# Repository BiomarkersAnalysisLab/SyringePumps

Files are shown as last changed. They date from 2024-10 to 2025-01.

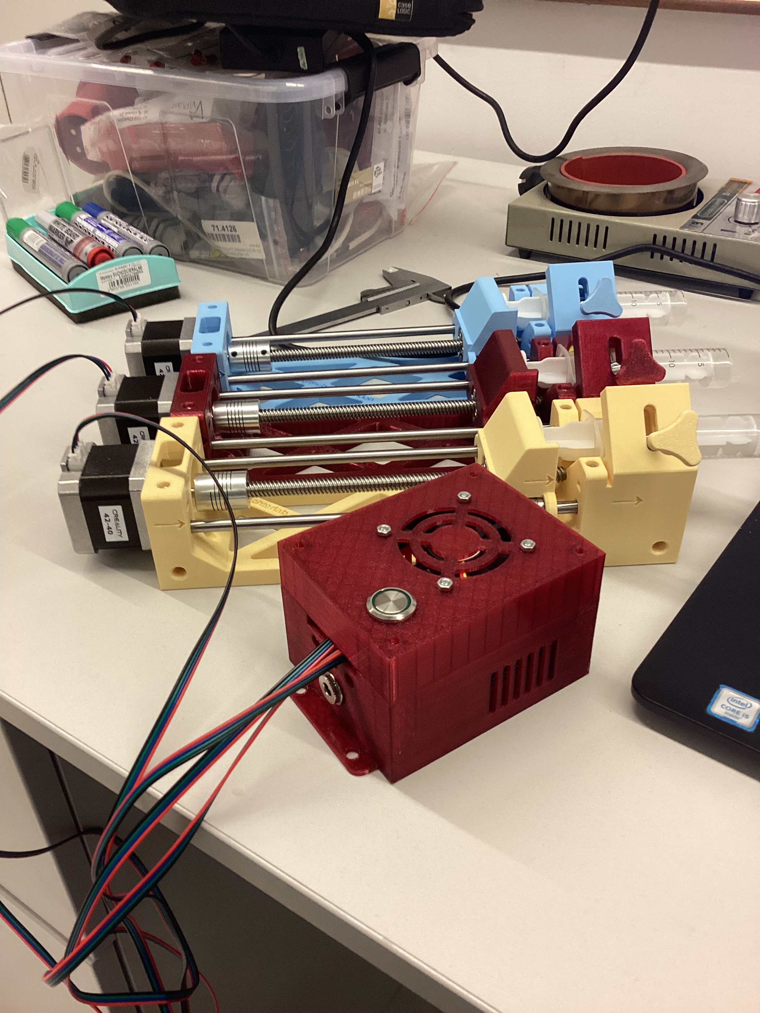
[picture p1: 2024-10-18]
Images/IMG_0060.JPEG

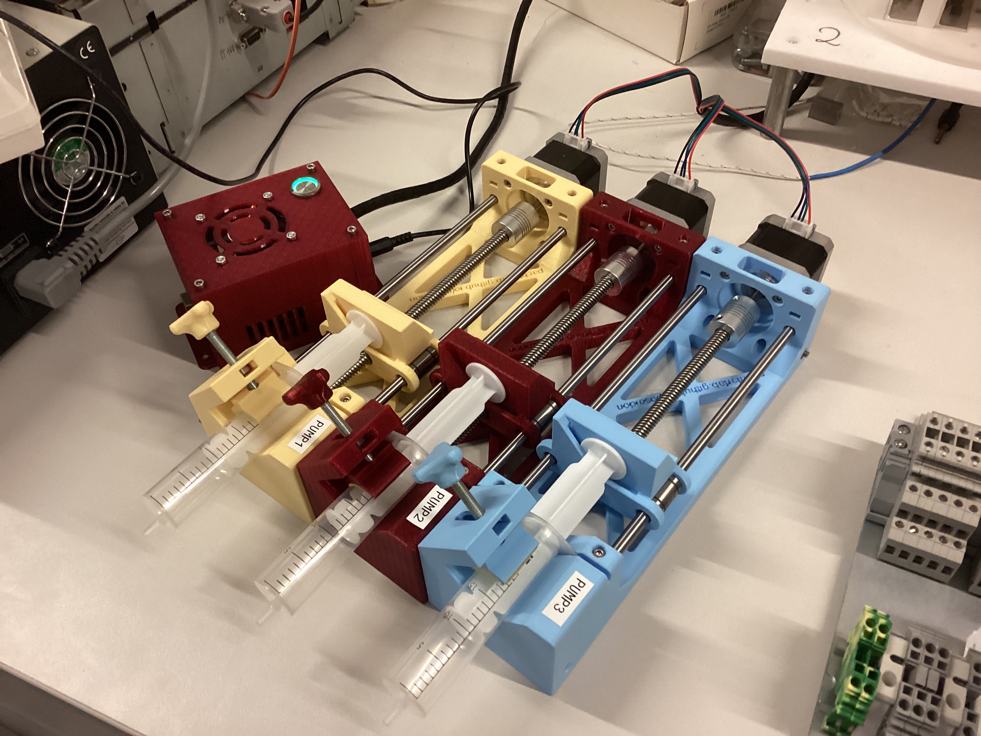
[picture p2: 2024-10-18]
Images/IMG_0064.JPEG

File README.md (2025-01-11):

Obraz1

Project realised by AGH Biomarkers Analysis Lab as a part of NCN SONATA BIS 12:  "Badania nad możliwością realizacji bioczujników do detekcji biomarkerów cukrzycy i NAFLD otrzymywanych w technologii TWD/GLAD" nr 2022/46/E/ST7/00008.

The main objective of the project was to create highly accurate pumps allowing precise dispension of fluids, with realatively low cost. 

The project was based on opensource project: https://github.com/pachterlab/poseidon/tree/release under the BSD-2-Clause license with modifications explained in "Changes_in_original_design.docx" file.

All the modified 3D models are available, and the test were conducted to prove the efficiency of the pumps.

pump


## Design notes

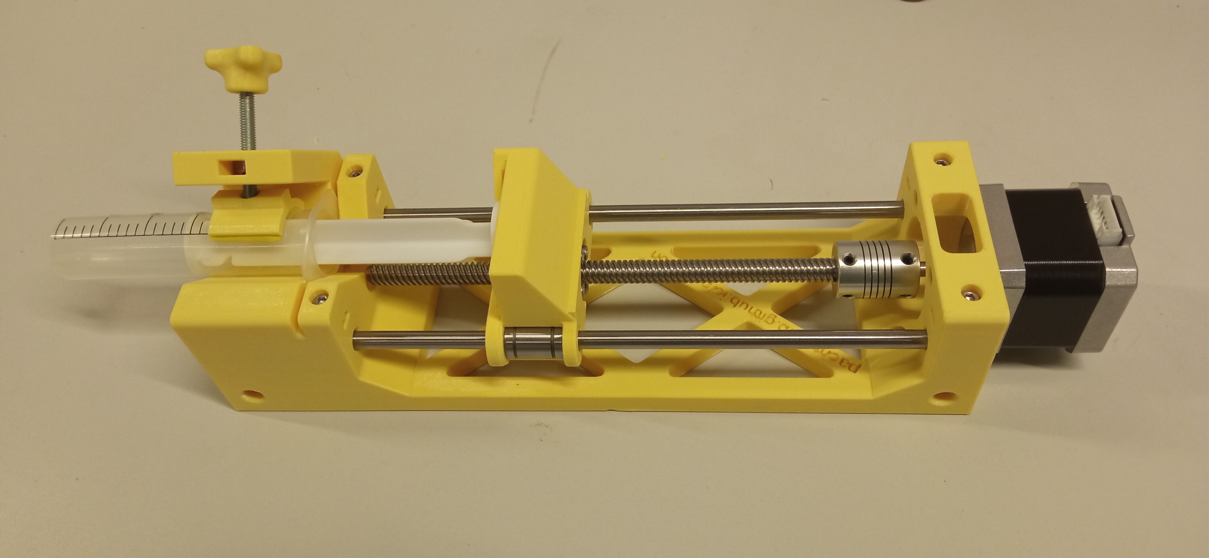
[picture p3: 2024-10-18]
Images/pump.jpg

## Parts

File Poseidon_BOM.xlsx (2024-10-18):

Poseidon Pumps
Total for 3 pumps | $120.70 |  |  |  | Per pump total | 43.45
Part Number | Item Description | Package Cost | Items for 3 pumps | Items per pump | Cost for 3 pumps | Cost per pump | Cost for single pump | Retailer | Items per pack | Price per item | Link
1 | Nema 17 Stepper Motor (Bipolar) | 33.99 | 3 | 1 | 33.99 | 11.33 | 33.99 | Amazon | 3 | 11.33 | https://www.amazon.com/Stepper-Holding-Printer-Beauty-Star/dp/B075S98D46
2 | 5mmx8mm Motor Shaft Coupling | 22 | 3 | 1 | 6.60 | 2.2 | 22 | Amazon | 10 | 2.20 | https://www.amazon.com/Aluminum-Flexible-Coupling-Printing-Pack/dp/B01EFFBM4I?s=industrial
3 | 6mm Steel Rod (length 200mm) | 7.12 | 6 | 2 | 21.36 | 7.12 | 7.12 | Amazon | 2 | 3.56 | https://www.amazon.com/Steel-Round-Turning-Lathe-200mm/dp/B00LUSVKVY
4 | 6mm Linear Bearing | 12.49 | 6 | 2 | 6.24 | 2.081666667 | 12.49 | Amazon | 12 | 1.04 | https://www.amazon.com/uxcell-6mmx12mmx19mm-Linear-Bushing-Bearing/dp/B01MTLSZFQ?s=industrial
5 | TR8x2 Lead Screw (length 170mm) | 9.14 | 3 | 1 | 5.48 | 1.828 | 9.14 | Amazon | 5 | 1.83 | https://www.amazon.com/uxcell-170mm-Stainless-Threaded-Fasteners/dp/B01M4L8JDC?s=industrial
6 | TR8x2 nut | 4.99 | 3 | 1 | 7.49 | 2.495 | 4.99 | Amazon | 2 | 2.50 | https://www.amazon.com/ReliaBot-Screw-Thread-Diameter-Printer/dp/B07TZCHP1N
7 | M3x16 socket head screws to mount motor | 6.35 | 24 | 4 | 1.52 | 0.254 | 6.35 | Amazon | 100 | 0.06 | https://www.amazon.com/Socket-Screw-Thread-stainless-100pcs/dp/B077XVVWYW
8 | M3x10 socket head screws (hold rod in place, length 10mm) | 7.8 | 12 | 4 | 1.70 | 0.5672727273 | 7.8 | Amazon | 55 | 0.14 | https://www.amazon.com/uxcell-M3x10mm-Thread-Stainless-Socket/dp/B01MFA9YEP?s=industrial
9 | M3 nut (hold rod in place) | 5.2 | 1 | 4 | 0.05 | 0.208 | 5.2 | Amazon | 100 | 0.05 | https://www.amazon.com/100Pcs-Female-Thread-Fastener-Silver/dp/B00GYS1SXU?s=industrial
10 | M5 knob (hold syringe in place) | 0 | 3 | 1 | 0.00 | 0 | 0 |  | 10 | 0.00 | https://www.thingiverse.com/thing:774472
11 | M5 nut | 6.99 | 3 | 1 | 0.21 | 0.0699 | 6.99 | Amazon | 100 | 0.07 | https://www.amazon.com/Nuts-M5-0-8-Stainless-Steel-100pcs/dp/B0BLBLBP93?sp_csd=d2lkZ2V0TmFtZT1zcF9hdGY
12 | M5 hex screw (length 40mm) | 8.99 | 3 | 1 | 1.08 | 0.3596 | 8.99 | Amazon | 25 | 0.36 | https://www.amazon.com/Socket-Screws-Stainless-Metric-Machine/dp/B09LYK1TH1
13 | Stepper driver a4988 | 7.99 | 3 | 1 | 7.99 | 2.663333333 | 7.99 | Amazon | 3 | 2.66 | https://www.amazon.com/WWZMDiB-Stepstick-Stepper-Printer-Suitable/dp/B0BFQZWT6R?sp_csd=d2lkZ2V0TmFtZT1zcF9hdGY
14 | 12V power unit (end stripped to fit CNC shield power input) | 13.99 | 3 | 1 | 13.99 | 4.663333333 | 13.99 | Amazon | 4 | 4.66 | https://www.amazon.com/Kastar-AC-Adapter-Power-LCD/dp/B003TUMDWG?s=electronics
15 | Arduino Uno | 8.99 | 1 | 0.33 | 8.99 | 2.9667 | 8.99 | Amazon | 1 | 8.99 | https://www.amazon.com/WWZMDiB-ATmega328P-microcontroller-Development-Compatible/dp/B0BV9XFQ5T
16 | CNC Shield | 7.99 | 1 | 0.33 | 4.00 | 1.31835 | 7.99 | Amazon | 2 | 4.00 | https://www.amazon.com/HiLetgo%C2%AE-Engraver-Printer-Expansion-Arduino/dp/B01D2HL9T8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
17 | 1M Bipolar Stepper Motor Cable 4pin Nema17 Stepper Motor Cable | 10 | 3 | 1 | 30 | 10 | 10 | Amazon | 1 |  | https://www.amazon.pl/SIENOC-krokowy-silnika-krokowego-dlugo%C5%9B%C4%87/dp/B077N4RYNX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

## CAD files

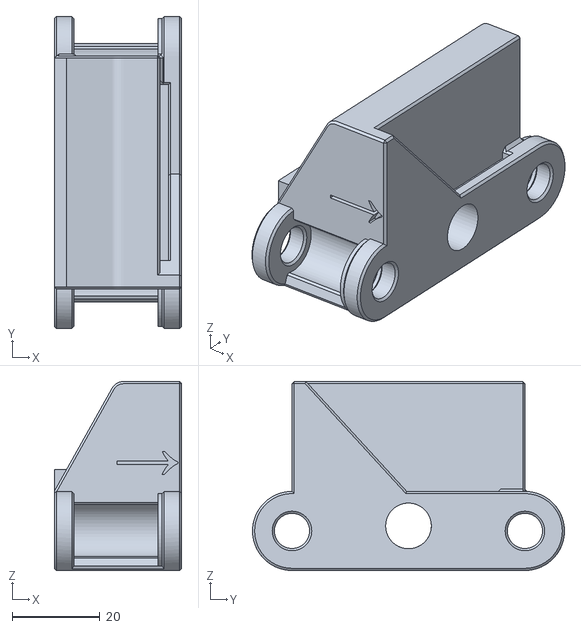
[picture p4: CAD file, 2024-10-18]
3D models/STL/Carriage+v1.stl
29.0 x 71.0 x 43.0

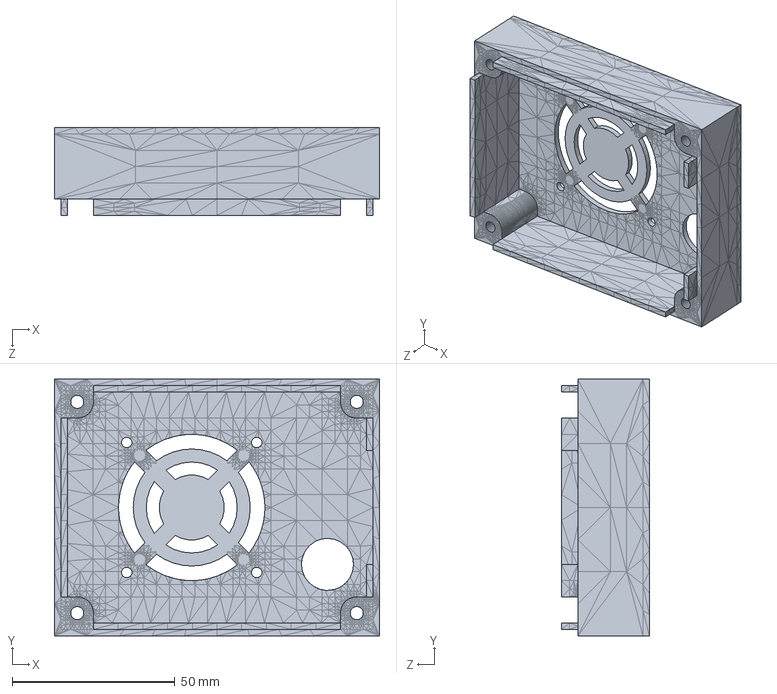
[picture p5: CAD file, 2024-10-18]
case-pump-driver/Modyfikacja/obudowa_gora_50x50.SLDPRT
100.0 x 79.0 x 27.0 mm

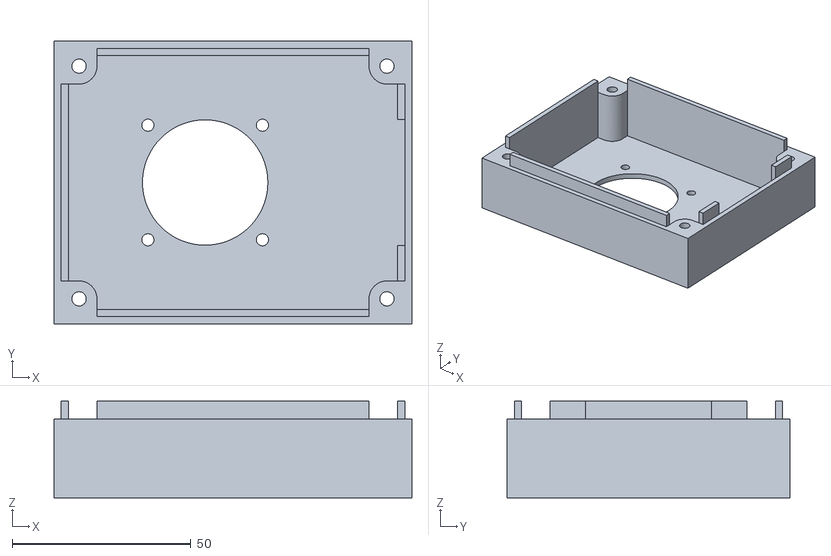
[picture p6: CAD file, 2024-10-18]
case-pump-driver/obudowa_gora_40x40.stl
100.0 x 79.0 x 27.0

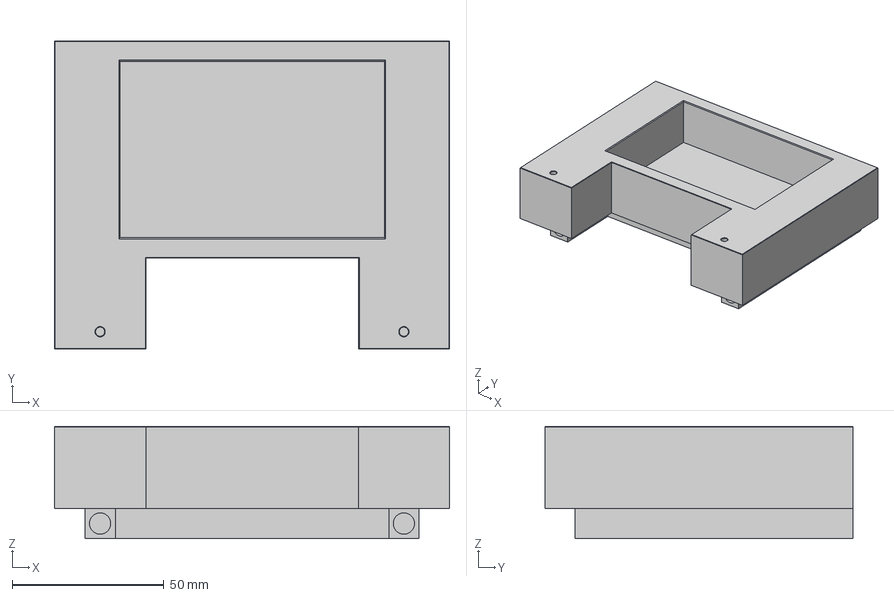
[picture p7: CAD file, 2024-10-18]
Microscope_Desk/STOLIK.step
130.0 x 101.5 x 37.0 mm

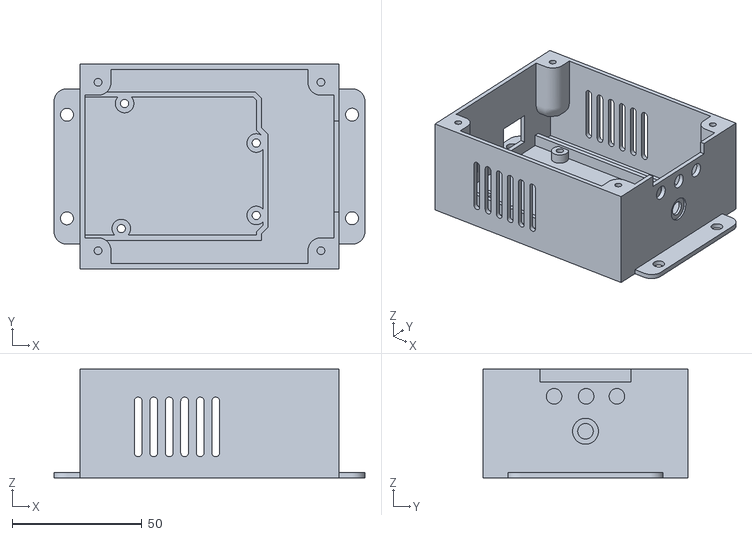
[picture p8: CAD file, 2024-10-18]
case-pump-driver/obudowa_dol.stl
120.0 x 79.0 x 42.0

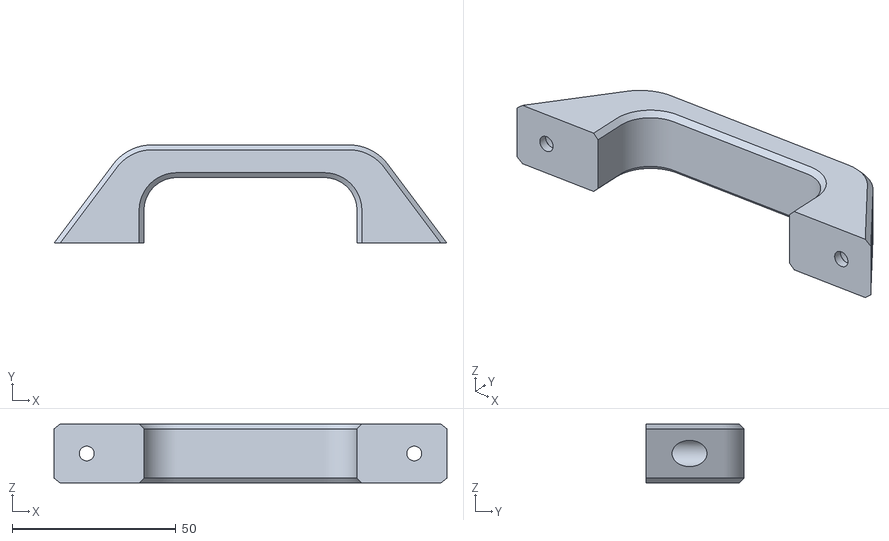
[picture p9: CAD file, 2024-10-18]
Microscope_Desk/Handle_MEDIUM.stl
120.0 x 30.0 x 18.0

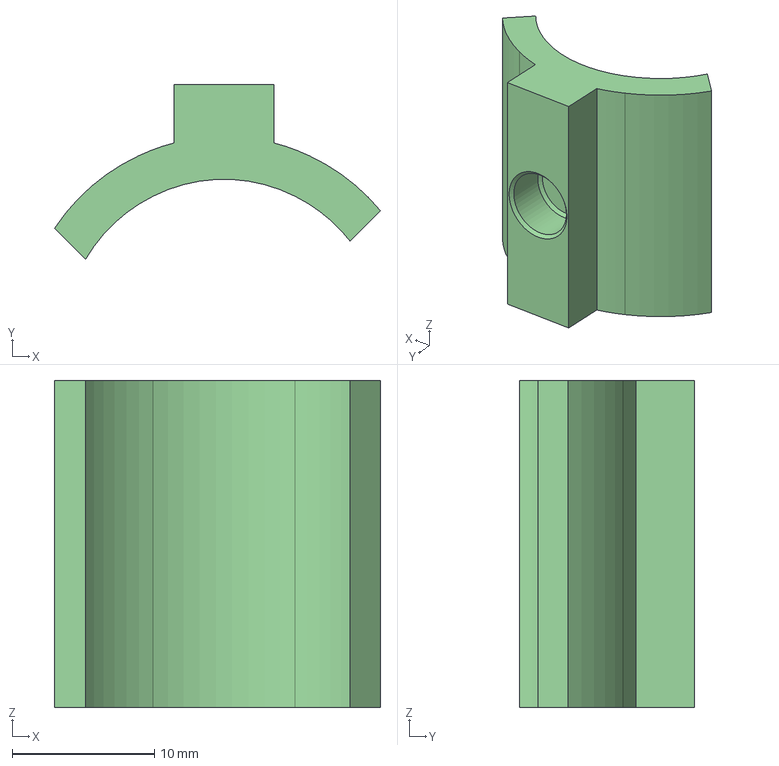
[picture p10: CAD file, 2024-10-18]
3D models/STEP/SYRINGE_HOLDER v1.step
22.9 x 12.3 x 23.0 mm

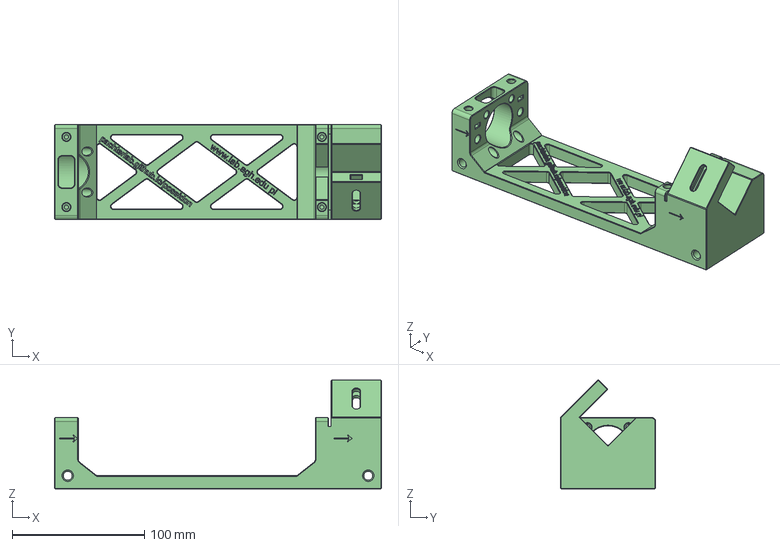
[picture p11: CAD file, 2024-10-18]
3D models/STEP/Pump_Base v4.step
247.0 x 72.0 x 82.3 mm

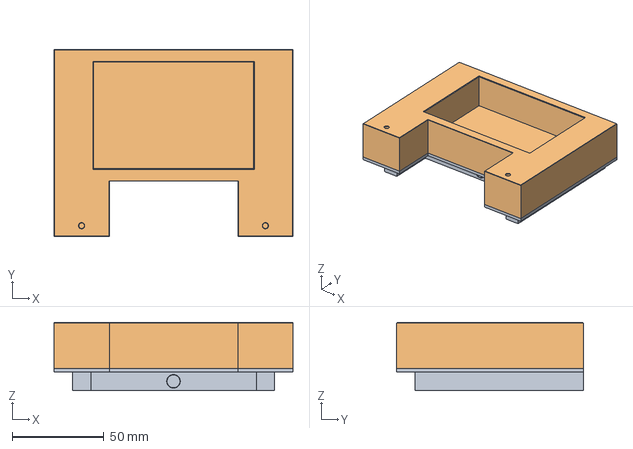
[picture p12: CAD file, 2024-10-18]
Microscope_Desk/STOLIK_FINAL v1.step
130.0 x 101.5 x 37.0 mm

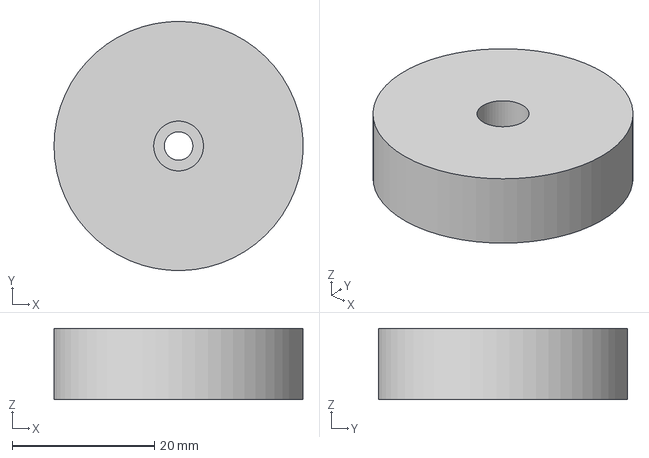
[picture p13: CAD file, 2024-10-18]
Microscope_Desk/LEG_1.step
35.0 x 35.0 x 10.0 mm

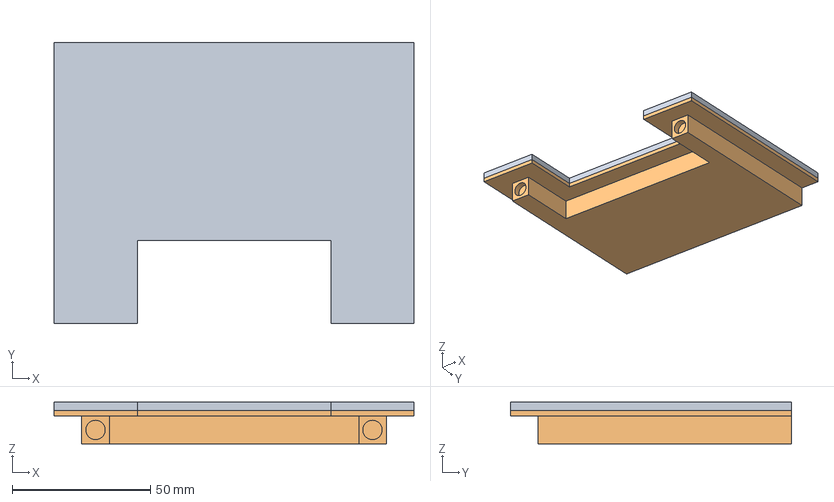
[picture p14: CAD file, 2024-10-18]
Microscope_Desk/STOLIK_2.step
130.0 x 101.5 x 15.0 mm

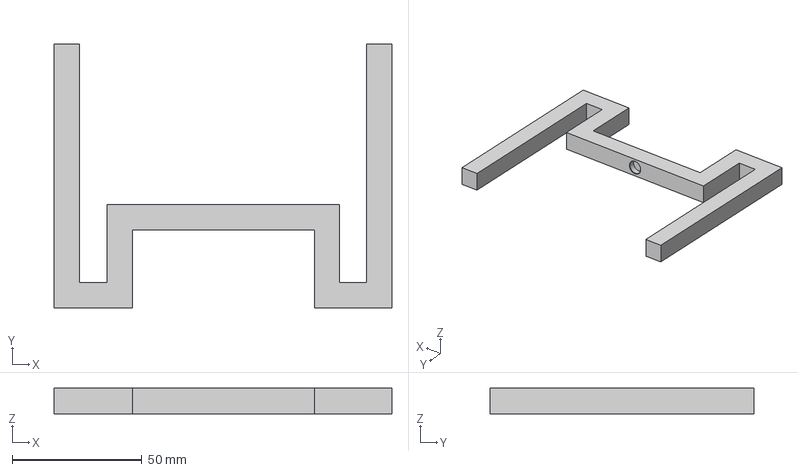
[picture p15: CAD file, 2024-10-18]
Microscope_Desk/STOLIK_PODS_FINAL v1.step
130.0 x 101.5 x 9.90 mm

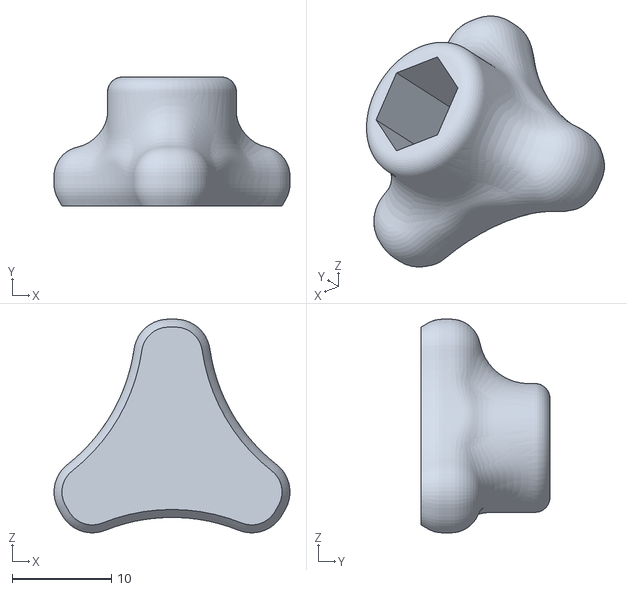
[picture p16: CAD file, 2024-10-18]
3D models/STEP/Improved_Knob_for_M5_Bolt.STL
23.8 x 13.0 x 21.6

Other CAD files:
3D models/STEP/Carriage v1 v6.step
Microscope_Desk/Microscope_Desk v7.step
Microscope_Desk/STOLIK_PODST_1.step
3D models/Fusion/Carriage+v1.f3z
3D models/Fusion/Pump_Base v4.f3z
3D models/Fusion/SYRINGE_HOLDER v1.f3z
3D models/STL/Pump_Base v4.stl
3D models/STL/SYRINGE_HOLDER v1.stl
case-pump-driver/Modyfikacja/obudowa_gora_50x50.STL

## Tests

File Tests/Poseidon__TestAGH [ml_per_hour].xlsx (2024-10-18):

Masa zlewki | Pompka |  |  |  |  |  |  | 0
20.1454 | NIEBIESKA
51.1761 | KREMOWA
28.6498 | BORDOWA
MIKROPIPETA [ml] |  | POMPKA KREMOWA [ml] |  | RÓŻNICA | BŁĄD [%] | RODZAJ PIPETY | ŚREDNI BŁĄD [%]
10 | 9.9846 | 10 | 9.8279 | 0.1567 | 0.1592 | PIPETA MAX 10ml | 0.1251
5 | 4.9929 | 5 | 4.8178 | 0.1751 | 0.1815 | PIPETA MAX 5ml
4 | 3.9586 | 4 | 3.8587 | 0.0999 | 0.1025 | PIPETA MAX 5ml
3 | 2.9755 | 3 | 2.8612 | 0.1143 | 0.1189 | PIPETA MAX 5ml
2 | 1.997 | 2 | 1.9178 | 0.0792 | 0.0825 | PIPETA MAX 5ml
1 | 0.9892 | 1 | 0.8932 | 0.0960 | 0.1063 | PIPETA MAX 5ml
MIKROPIPETA [ml] |  | POMPKA BORDOWA [ml] |  | RÓŻNICA | BŁĄD [%] | RODZAJ PIPETY | ŚREDNI BŁĄD [%]
10 | 9.9846 | 10 | 9.7860 | 0.1986 | 0.2026304476 | PIPETA MAX 10ml | 0.09538528053
5 | 4.9929 | 5 | 4.8745 | 0.1184 | 0.121275897 | PIPETA MAX 5ml
4 | 3.9586 | 4 | 3.9151 | 0.0435 | 0.04398332099 | PIPETA MAX 5ml
3 | 2.9755 | 3 | 2.9007 | 0.0748 | 0.07672885855 | PIPETA MAX 5ml
2 | 1.997 | 2 | 1.9280 | 0.0690 | 0.07146939834 | PIPETA MAX 5ml
1 | 0.9892 | 1 | 0.9360 | 0.0532 | 0.05622376068 | PIPETA MAX 5ml
MIKROPIPETA [ml] |  | POMPKA NIEBIESKA [ml] |  | RÓŻNICA | BŁĄD [%] | RODZAJ PIPETY | ŚREDNI BŁĄD [%]
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

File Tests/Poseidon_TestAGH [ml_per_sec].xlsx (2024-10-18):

MIKROPIPETA [ml] |  | POMPKA KREMOWA [ml] |  | RÓŻNICA | BŁĄD [%] | RODZAJ PIPETY | ŚREDNI BŁĄD [%]
10 | 10.0025 | 10 | 9.8303 | 0.1722 | 0.1752164736 | PIPETA MAX 10ml | 0.0456
5 | 4.9462 | 5 | 4.9541 | -0.0079 | -0.007887402354 | PIPETA MAX 5ml
4 | 3.9936 | 4 | 3.9504 | 0.0432 | 0.04367241798 | PIPETA MAX 5ml
3 | 2.979 | 3 | 2.9547 | 0.0243 | 0.0244998477 | PIPETA MAX 5ml
2 | 1.9744 | 2 | 1.9674 | 0.007 | 0.007024905967 | PIPETA MAX 5ml
1 | 0.9887 | 1 | 0.9735 | 0.0152 | 0.01543732922 | PIPETA MAX 5ml
MIKROPIPETA [ml] |  | POMPKA BORDOWA [ml] |  | RÓŻNICA | BŁĄD [%] | RODZAJ PIPETY | ŚREDNI BŁĄD [%]
10 | 9.957 | 10 | 9.8724 | 0.0846 | 0.08532496657 | PIPETA MAX 10ml | 0.0697
5 | 4.9737 | 5 | 4.8951 | 0.0786 | 0.07986207023 | PIPETA MAX 5ml
4 | 3.9622 | 4 | 3.8868 | 0.0754 | 0.07686268396 | PIPETA MAX 5ml
3 | 2.9875 | 3 | 2.9128 | 0.0747 | 0.0766157134 | PIPETA MAX 5ml
2 | 2.0034 | 2 | 1.9403 | 0.0631 | 0.06515205896 | PIPETA MAX 5ml
1 | 0.9983 | 1 | 0.9648 | 0.0335 | 0.03466319444 | PIPETA MAX 5ml
MIKROPIPETA [ml] |  | POMPKA NIEBIESKA [ml] |  | RÓŻNICA | BŁĄD [%] | RODZAJ PIPETY | ŚREDNI BŁĄD [%]
10 | 9.9041 | 10 | 9.8152 | 0.0889 | 0.08970520112 | PIPETA MAX 10ml | 0.0486
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

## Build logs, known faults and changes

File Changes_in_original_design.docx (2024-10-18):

# Changes in original posejdon design (https://github.com/pachterlab/poseidon/tree/release)

BASE

1. All socket head screws were swapped for M3x16 (The holes in which the screws are mounted were deepend accordingly)
2. M6 threaded rod changed to TR8x2 screw (8mm pitch)
3. The hole below the syringe (Where the lead screw is supposed to go) was rounded and the diameter was changed from 3.5mm to 6.5mm
4. The syringe holder module was changed entirely (both the knob and the holder itself) and the elastic foam was added in order to ensure stability of the syringe.
5. Knob for M5 comes from Thingiverse project (Compact M5 Nut Knob

by B_EMME3D https://www.thingiverse.com/thing:774472 )

CARRIAGE

1. The crosswise hole in the middle of the carriage as well as on the bottom of it were sealed shut.
2. The hole allowing the lead screw to pass through the carriage was enlarged and deepend to fit the TR8x2 nut. 4 additional holes were made for M3x10 screws to hold the nut in place
3. The cavities made for the linear bearings were shortened from 20mm to 19.1mm (0.05mm free space on both sides of the bearings)
4. The back of the carriage was drawn-out to fit the T8x2 nut
5. Pump cover slide element was removed from the project

SOFTWARE

1. steps2mm and mm2steps functions were changed to match the screw pitch of the T8x2 lead screw. One revolution of the motor shaft equals 8mm displacement of the carriage.
2. The area of the syringe was changed accordingly to the used model (It is important to establish the area of the model you will be using in your project beforehand).
3. The title of the GUI was changed to "Poseidon Pumps Controller - Biomarkers Analysis Lab AGH 2024"

Every part in the project was printed out with PETG 3 Perimeters and 25% infill.

More information regarding the specific changes from the original design can be found either in the BOM or the 3D models themselves.

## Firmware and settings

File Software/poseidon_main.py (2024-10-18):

#!/usr/bin/env python
# -*- coding: utf-8 -*-

import serial
import time
import glob
import sys
from datetime import datetime
import time
import os
# This gets the Qt stuff

from PyQt5 import QtCore, QtGui, QtWidgets
from PyQt5.QtWidgets import QMainWindow, QApplication, QFileDialog

import cv2
# note, had to use version 3.2.0.8 otherwise it had its own
# pyqt packages that conflicted with mine

import numpy as np
from decimal import Decimal
# This is our window from QtCreator
import poseidon_controller_gui
import pdb
import traceback, sys

# ##############################
# MULTITHREADING : SIGNALS CLASS
# ##############################s
class WorkerSignals(QtCore.QObject):
    '''
    Defines the signals available from a running worker thread.

    Supported signals are:

    finished
        No data

    error
        `tuple` (exctype, value, traceback.format_exc() )

    result
        `object` data returned from processing, anything

    '''
    finished = QtCore.pyqtSignal()
    error = QtCore.pyqtSignal(tuple)
    result = QtCore.pyqtSignal(object)
    progress = QtCore.pyqtSignal(int)

# #############################
# MULTITHREADING : WORKER CLASS
# #############################


class Thread(QtCore.QThread):
	def __init__(self, fn, *args, **kwargs):
		parent = None
		super(Thread, self).__init__(parent)
		self.runs = True
		self.fn = fn
		self.args = args
		self.kwargs = kwargs
		self.signals = WorkerSignals()

	def run(self):
		try:
			#self.serial.flushInput()
			#self.serial.flushOutput()
			result = self.fn(*self.args, **self.kwargs)
		except:
			traceback.print_exc()
			exctype, value = sys.exc_info()[:2]
			self.signals.error.emit((exctype, value, traceback.format_exc()))
		else:
			self.signals.result.emit(result)  # Return the result of the processing
		finally:
			self.signals.finished.emit()  # Done
			self.stop()

			print("Job completed")

	def stop(self):
		self.runs = False




# #####################################
# ERROR HANDLING : CANNOT CONNECT CLASS
# #####################################
class CannotConnectException(Exception):
	pass

# #######################
# GUI : MAIN WINDOW CLASS
# #######################
class MainWindow(QtWidgets.QMainWindow, poseidon_controller_gui.Ui_MainWindow):

	# =======================================================
	# INITIALIZING : The UI and setting some needed variables
	# =======================================================
	def __init__(self):

		# Setting the UI to a class variable and connecting all GUI Components
		super(MainWindow, self).__init__()
		self.ui = poseidon_controller_gui.Ui_MainWindow()
		self.ui.setupUi(self)

		# Put comments here
		self.populate_microstepping()
		self.populate_syringe_sizes()
		self.populate_pump_jog_delta()
		self.populate_pump_units()
		self.setting_variables()
		self.populate_ports()
		self.set_port()



		self.connect_all_gui_components()
		self.grey_out_components()

		# Declaring start, mid, and end marker for sending code to Arduino
		self.startMarker = 60# <
		self.endMarker = 62  # ,F,0.0>
		self.midMarker = 44 # ,

		# Initializing multithreading to allow parallel operations
		self.threadpool = QtCore.QThreadPool()
		print("Multithreading with maximum %d threads" % self.threadpool.maxThreadCount())


		# Camera setup
		self.timer = QtCore.QTimer()
		self.timer.setInterval(1000)
		self.timer.timeout.connect(self.recurring_timer)
		self.timer.start()
		self.counter = 0

		# Random other things I need
		self.image = None
		#self.microstepping = 1
		#print(self.microstepping)


	def recurring_timer(self):
		self.counter +=1

	# =============================
	# SETTING : important variables
	# =============================
	def setting_variables(self):

		self.set_p1_syringe()
		self.set_p2_syringe()
		self.set_p3_syringe()



		#self.set_p1_units()
		#self.set_p2_units()
		#self.set_p3_units()

		self.is_p1_active = False
		self.is_p2_active = False
		self.is_p3_active = False

		self.experiment_notes = ""

	def thread_finished(self, th):
		print("Your thread has completed. Now terminating..")
		th.stop()
		print("Thread has been terminated.")
		print("=============================\n\n")
		# here is where you need to end the thread


	# ===================================
	# CONNECTING : all the GUI Components
	# ===================================
	def connect_all_gui_components(self):

		# ~~~~~~~~~~~~~~~
		# MAIN : MENU BAR
		# ~~~~~~~~~~~~~~~
		self.ui.load_settings_BTN.triggered.connect(self.load_settings)
		self.ui.save_settings_BTN.triggered.connect(self.save_settings)

		# ~~~~~~~~~~~~~~~~
		# TAB : Controller
		# ~~~~~~~~~~~~~~~~

		# Px active checkboxes
		self.ui.p1_activate_CHECKBOX.stateChanged.connect(self.toggle_p1_activation)
		self.ui.p2_activate_CHECKBOX.stateChanged.connect(self.toggle_p2_activation)
		self.ui.p3_activate_CHECKBOX.stateChanged.connect(self.toggle_p3_activation)

		# Px display (TODO)

		# Px syringe display
		self.ui.p1_syringe_DROPDOWN.currentIndexChanged.connect(self.display_p1_syringe)
		self.ui.p2_syringe_DROPDOWN.currentIndexChanged.connect(self.display_p2_syringe)
		self.ui.p3_syringe_DROPDOWN.currentIndexChanged.connect(self.display_p3_syringe)


		# Px speed display
		self.ui.p1_units_DROPDOWN.currentIndexChanged.connect(self.display_p1_speed)
		self.ui.p2_units_DROPDOWN.currentIndexChanged.connect(self.display_p2_speed)
		self.ui.p3_units_DROPDOWN.currentIndexChanged.connect(self.display_p3_speed)



		#self.populate_pump_units()

		# Px amount
		self.ui.p1_amount_INPUT.valueChanged.connect(self.set_p1_amount)
		self.ui.p2_amount_INPUT.valueChanged.connect(self.set_p2_amount)
		self.ui.p3_amount_INPUT.valueChanged.connect(self.set_p3_amount)

		# Px jog delta
		#self.ui.p1_jog_delta_INPUT.valueChanged.connect(self.set_p1_jog_delta)
		#self.ui.p2_jog_delta_INPUT.valueChanged.connect(self.set_p2_jog_delta)
		#self.ui.p3_jog_delta_INPUT.valueChanged.connect(self.set_p3_jog_delta)

		# Action buttons
		self.ui.run_BTN.clicked.connect(self.run)


		self.ui.pause_BTN.clicked.connect(self.pause)


		self.ui.zero_BTN.clicked.connect(self.zero)
		self.ui.stop_BTN.clicked.connect(self.stop)


		self.ui.jog_plus_BTN.clicked.connect(lambda:self.jog(self.ui.jog_plus_BTN))
		self.ui.jog_minus_BTN.clicked.connect(lambda:self.jog(self.ui.jog_minus_BTN))

		# Set coordinate system
		self.ui.absolute_RADIO.toggled.connect(lambda:self.set_coordinate(self.ui.absolute_RADIO))
		self.ui.incremental_RADIO.toggled.connect(lambda:self.set_coordinate(self.ui.incremental_RADIO))

		# ~~~~~~~~~~~~
		# TAB : Camera
		# ~~~~~~~~~~~~

		# Setting camera action buttons
		self.ui.camera_connect_BTN.clicked.connect(self.start_camera)
		self.ui.camera_disconnect_BTN.clicked.connect(self.stop_camera)
		self.ui.camera_capture_image_BTN.clicked.connect(self.save_image)

		# ~~~~~~~~~~~
		# TAB : Setup
		# ~~~~~~~~~~~

		# Port, first populate it then connect it (population done earlier)
		self.ui.refresh_ports_BTN.clicked.connect(self.refresh_ports)
		self.ui.port_DROPDOWN.currentIndexChanged.connect(self.set_port)

		self.ui.experiment_notes.editingFinished.connect(self.set_experiment_notes)

		# Set the microstepping value, default is 1
		self.ui.microstepping_DROPDOWN.currentIndexChanged.connect(self.set_microstepping)

		# Set the log file name
		self.date_string =  datetime.now().strftime("%Y-%m-%d %H:%M:%S")
		self.date_string = self.date_string.replace(":","_") # Replace semicolons with underscores

		# Px syringe size, populate then connect (population done earlier)
		self.ui.p1_syringe_DROPDOWN.currentIndexChanged.connect(self.set_p1_syringe)
		self.ui.p2_syringe_DROPDOWN.currentIndexChanged.connect(self.set_p2_syringe)
		self.ui.p3_syringe_DROPDOWN.currentIndexChanged.connect(self.set_p3_syringe)
		# warning to send the info to the controller
		self.ui.p1_syringe_DROPDOWN.currentIndexChanged.connect(self.send_p1_warning)
		self.ui.p2_syringe_DROPDOWN.currentIndexChanged.connect(self.send_p2_warning)
		self.ui.p3_syringe_DROPDOWN.currentIndexChanged.connect(self.send_p3_warning)

		# Px units
		self.ui.p1_units_DROPDOWN.currentIndexChanged.connect(self.set_p1_units)
		self.ui.p2_units_DROPDOWN.currentIndexChanged.connect(self.set_p2_units)
		self.ui.p3_units_DROPDOWN.currentIndexChanged.connect(self.set_p3_units)
		# warning to send the info to the controller
		self.ui.p1_units_DROPDOWN.currentIndexChanged.connect(self.send_p1_warning)
		self.ui.p2_units_DROPDOWN.currentIndexChanged.connect(self.send_p2_warning)
		self.ui.p3_units_DROPDOWN.currentIndexChanged.connect(self.send_p3_warning)

		# Px speed
		self.ui.p1_speed_INPUT.valueChanged.connect(self.set_p1_speed)
		self.ui.p2_speed_INPUT.valueChanged.connect(self.set_p2_speed)
		self.ui.p3_speed_INPUT.valueChanged.connect(self.set_p3_speed)
		# warning to send the info to the controller
		self.ui.p1_speed_INPUT.valueChanged.connect(self.send_p1_warning)
		self.ui.p2_speed_INPUT.valueChanged.connect(self.send_p2_warning)
		self.ui.p3_speed_INPUT.valueChanged.connect(self.send_p3_warning)

		# Px accel
		self.ui.p1_accel_INPUT.valueChanged.connect(self.set_p1_accel)
		self.ui.p2_accel_INPUT.valueChanged.connect(self.set_p2_accel)
		self.ui.p3_accel_INPUT.valueChanged.connect(self.set_p3_accel)
		# warning to send the info to the controller
		self.ui.p1_accel_INPUT.valueChanged.connect(self.send_p1_warning)
		self.ui.p2_accel_INPUT.valueChanged.connect(self.send_p2_warning)
		self.ui.p3_accel_INPUT.valueChanged.connect(self.send_p3_warning)

		# Px jog delta (setup)
		self.ui.p1_setup_jog_delta_INPUT.currentIndexChanged.connect(self.set_p1_setup_jog_delta)
		self.ui.p2_setup_jog_delta_INPUT.currentIndexChanged.connect(self.set_p2_setup_jog_delta)
		self.ui.p3_setup_jog_delta_INPUT.currentIndexChanged.connect(self.set_p3_setup_jog_delta)
		# warning to send the info to the contorller
		self.ui.p1_setup_jog_delta_INPUT.currentIndexChanged.connect(self.send_p1_warning)
		self.ui.p2_setup_jog_delta_INPUT.currentIndexChanged.connect(self.send_p2_warning)
		self.ui.p3_setup_jog_delta_INPUT.currentIndexChanged.connect(self.send_p3_warning)


		# Px send settings
		self.ui.p1_setup_send_BTN.clicked.connect(self.send_p1_settings)
		self.ui.p2_setup_send_BTN.clicked.connect(self.send_p2_settings)
		self.ui.p3_setup_send_BTN.clicked.connect(self.send_p3_settings)
		# remove warning to send settings
		self.ui.p1_setup_send_BTN.clicked.connect(self.send_p1_success)
		self.ui.p2_setup_send_BTN.clicked.connect(self.send_p2_success)
		self.ui.p3_setup_send_BTN.clicked.connect(self.send_p3_success)

		# Connect to arduino
		self.ui.connect_BTN.clicked.connect(self.connect)
		self.ui.disconnect_BTN.clicked.connect(self.disconnect)

		# Send all the settings at once
		self.ui.send_all_BTN.clicked.connect(self.send_all)

	def send_p1_warning(self):
		self.ui.p1_setup_send_BTN.setStyleSheet("background-color: green; color: black")

	def send_p2_warning(self):
		self.ui.p2_setup_send_BTN.setStyleSheet("background-color: green; color: black")

	def send_p3_warning(self):
		self.ui.p3_setup_send_BTN.setStyleSheet("background-color: green; color: black")

	def send_p1_success(self):
		self.ui.p1_setup_send_BTN.setStyleSheet("background-color: none")

	def send_p2_success(self):
		self.ui.p2_setup_send_BTN.setStyleSheet("background-color: none")

	def send_p3_success(self):
		self.ui.p3_setup_send_BTN.setStyleSheet("background-color: none")

	def grey_out_components(self):
		# ~~~~~~~~~~~~~~~~
		# TAB : Controller
		# ~~~~~~~~~~~~~~~~
		self.ui.run_BTN.setEnabled(False)
		self.ui.pause_BTN.setEnabled(False)
		self.ui.zero_BTN.setEnabled(False)
		self.ui.stop_BTN.setEnabled(False)
		self.ui.jog_plus_BTN.setEnabled(False)
		self.ui.jog_minus_BTN.setEnabled(False)

		# ~~~~~~~~~~~~~~~~
		# TAB : Setup
		# ~~~~~~~~~~~~~~~~
		self.ui.p1_setup_send_BTN.setEnabled(False)
		self.ui.p2_setup_send_BTN.setEnabled(False)
		self.ui.p3_setup_send_BTN.setEnabled(False)
		self.ui.send_all_BTN.setEnabled(False)

	def ungrey_out_components(self):
		# ~~~~~~~~~~~~~~~~
		# TAB : Controller
		# ~~~~~~~~~~~~~~~~
		self.ui.run_BTN.setEnabled(True)
		self.ui.pause_BTN.setEnabled(True)
		self.ui.zero_BTN.setEnabled(True)
		self.ui.stop_BTN.setEnabled(True)
		self.ui.jog_plus_BTN.setEnabled(True)
		self.ui.jog_minus_BTN.setEnabled(True)

		self.ui.run_BTN.setStyleSheet("background-color: green; color: black")
		self.ui.pause_BTN.setStyleSheet("background-color: yellow; color: black")
		self.ui.stop_BTN.setStyleSheet("background-color: red; color: black")

		# ~~~~~~~~~~~~~~~~
		# TAB : Setup
		# ~~~~~~~~~~~~~~~~
		self.ui.p1_setup_send_BTN.setEnabled(True)
		self.ui.p2_setup_send_BTN.setEnabled(True)
		self.ui.p3_setup_send_BTN.setEnabled(True)
		self.ui.send_all_BTN.setEnabled(True)
	# ======================
	# FUNCTIONS : Controller
	# ======================

	def toggle_p1_activation(self):
		if self.ui.p1_activate_CHECKBOX.isChecked():
			self.is_p1_active = True
		else:
			self.is_p1_active = False

	def toggle_p2_activation(self):
		if self.ui.p2_activate_CHECKBOX.isChecked():
			self.is_p2_active = True
		else:
			self.is_p2_active = False

	def toggle_p3_activation(self):
		if self.ui.p3_activate_CHECKBOX.isChecked():
			self.is_p3_active = True
		else:
			self.is_p3_active = False

	# Get a list of active pumps (IDK if this is the best way to do this)
	def get_active_pumps(self):
		pumps_list = [self.is_p1_active, self.is_p2_active, self.is_p3_active]
		active_pumps = [i+1 for i in range(len(pumps_list)) if pumps_list[i]]
		return active_pumps

	def display_p1_syringe(self):
		self.ui.p1_syringe_LABEL.setText(self.ui.p1_syringe_DROPDOWN.currentText())
	def display_p2_syringe(self):
		self.ui.p2_syringe_LABEL.setText(self.ui.p2_syringe_DROPDOWN.currentText())
	def display_p3_syringe(self):
		self.ui.p3_syringe_LABEL.setText(self.ui.p3_syringe_DROPDOWN.currentText())

	def display_p1_speed(self):
		self.ui.p1_units_LABEL.setText(str(self.p1_speed) + " " + self.ui.p1_units_DROPDOWN.currentText())
	def display_p2_speed(self):
		self.ui.p2_units_LABEL.setText(str(self.p2_speed) + " " + self.ui.p2_units_DROPDOWN.currentText())
	def display_p3_speed(self):
		self.ui.p3_units_LABEL.setText(str(self.p3_speed) + " " + self.ui.p3_units_DROPDOWN.currentText())

	# Set Px distance to move	
	def set_p1_amount(self):
		self.p1_amount = self.ui.p1_amount_INPUT.value()
	def set_p2_amount(self):
		self.p2_amount = self.ui.p2_amount_INPUT.value()
	def set_p3_amount(self):
		self.p3_amount = self.ui.p3_amount_INPUT.value()

	# Set Px jog delta
	#def set_p1_jog_delta(self):
	#	self.p1_jog_delta = self.ui.p1_jog_delta_INPUT.value()
	#def set_p2_jog_delta(self):
	#	self.p2_jog_delta = self.ui.p2_jog_delta_INPUT.value()
	#def set_p3_jog_delta(self):
	#	self.p3_jog_delta = self.ui.p3_jog_delta_INPUT.value()

	# Set the coordinate system for the pump
	def set_coordinate(self, radio):
		if radio.text() == "Abs.":
			if radio.isChecked():
				self.coordinate = "absolute"
		if radio.text() == "Incr.":
			if radio.isChecked():
				self.coordinate = "incremental"

	def run(self):
		self.statusBar().showMessage("You clicked RUN")
		testData = []

		active_pumps = self.get_active_pumps()
		if len(active_pumps) > 0:

			p1_input_displacement = str(self.convert_displacement(self.p1_amount, self.p1_units, self.p1_syringe_area, self.microstepping))
			p2_input_displacement = str(self.convert_displacement(self.p2_amount, self.p2_units, self.p2_syringe_area, self.microstepping))
			p3_input_displacement = str(self.convert_displacement(self.p3_amount, self.p3_units, self.p3_syringe_area, self.microstepping))

			pumps_2_run = ''.join(map(str,active_pumps))

			cmd = "<RUN,DIST,"+pumps_2_run+",0.0,F," + p1_input_displacement + "," + p2_input_displacement + "," + p3_input_displacement + ">"

			testData.append(cmd)

			print("Sending RUN command..")
			thread = Thread(self.runTest, testData)
			thread.finished.connect(lambda:self.thread_finished(thread))
			thread.start()
			print("RUN command sent.")
		else:
			self.statusBar().showMessage("No pumps enabled.")

	# Clean up this text
	def pause(self):
		active_pumps = self.get_active_pumps()
		pumps_2_run = ''.join(map(str,active_pumps))

		if self.ui.pause_BTN.text() == "Pause":
			self.statusBar().showMessage("You clicked PAUSE")
			testData = []
			cmd = "<PAUSE,BLAH," + pumps_2_run + ",BLAH,F,0.0,0.0,0.0>"
			testData.append(cmd)

			print("Sending PAUSE command..")
			thread = Thread(self.runTest, testData)
			thread.finished.connect(lambda:self.thread_finished(thread))
			thread.start()
			print("PAUSE command sent.")

			self.ui.pause_BTN.setText("Resume")

		elif self.ui.pause_BTN.text() == "Resume":
			self.statusBar().showMessage("You clicked RESUME")
			testData = []
			cmd = "<RESUME,BLAH," + pumps_2_run + ",BLAH,F,0.0,0.0,0.0>"
			testData.append(cmd)

			print("Sending RESUME command..")
			thread = Thread(self.runTest, testData)
			thread.finished.connect(lambda:self.thread_finished(thread))
			thread.start()
			print("RESUME command sent.")

			self.ui.pause_BTN.setText("Pause")

	# fix
	def zero(self):
		self.statusBar().showMessage("You clicked ZERO")
		testData = []

		cmd = "<ZERO,BLAH,BLAH,BLAH,F,0.0,0.0,0.0>"

		print("Sending ZERO command..")
		thread = Thread(self.runTest, testData)
		thread.finished.connect(lambda:self.thread_finished(thread))
		thread.start()
		print("ZERO command sent.")


	def stop(self):
		self.statusBar().showMessage("You clicked STOP")
		cmd = "<STOP,BLAH,BLAH,BLAH,F,0.0,0.0,0.0>"

		print("Sending STOP command..")
		thread = Thread(self.send_single_command, cmd)
		thread.finished.connect(lambda:self.thread_finished(thread))
		thread.start()
		print("STOP command sent.")

	def jog(self, btn):
		self.statusBar().showMessage("You clicked JOG")
		#self.serial.flushInput()
		testData = []
		active_pumps = self.get_active_pumps()
		if len(active_pumps) > 0:
			pumps_2_run = ''.join(map(str,active_pumps))

			one_jog = str(self.p1_setup_jog_delta_to_send)
			two_jog = str(self.p2_setup_jog_delta_to_send)
			three_jog = str(self.p3_setup_jog_delta_to_send)

			if btn.text() == "Jog +":
				self.statusBar().showMessage("You clicked JOG +")
				f_cmd = "<RUN,DIST," + pumps_2_run +",0,F," + one_jog + "," + two_jog + "," + three_jog + ">"
				testData.append(f_cmd)

				print("Sending JOG command..")

				thread = Thread(self.runTest, testData)
				thread.finished.connect(lambda:self.thread_finished(thread))
				thread.start()
				print("JOG command sent.")

			elif btn.text() == "Jog -":
				self.statusBar().showMessage("You clicked JOG -")
				b_cmd = "<RUN,DIST," + pumps_2_run +",0,B," + one_jog + "," + two_jog + "," + three_jog + ">"
				testData.append(b_cmd)

				print("Sending JOG command..")
				thread = Thread(self.runTest, testData)
				thread.finished.connect(lambda:self.thread_finished(thread))
				thread.start()
				print("JOG command sent.")
		else:
			self.statusBar().showMessage("No pumps enabled.")

	# ======================
	# FUNCTIONS : Camera
	# ======================
	# Initialize the camera
	def start_camera(self):
		self.statusBar().showMessage("You clicked START CAMERA")
		camera_port = 0
		self.capture = cv2.VideoCapture(camera_port)
		#TODO check the native resolution of the camera and scale the size down here
		self.capture.set(cv2.CAP_PROP_FRAME_HEIGHT, 800)
		self.capture.set(cv2.CAP_PROP_FRAME_WIDTH, 400)

		self.timer = QtCore.QTimer(self)
		self.timer.timeout.connect(self.update_frame)
		self.timer.start(5)

	# Update frame function
	def update_frame(self):
		ret, self.image = self.capture.read()
		self.image = cv2.flip(self.image, 1)
		self.display_image(self.image, 1)

	# Display image in frame
	def display_image(self, image, window=1):
		qformat = QtGui.QImage.Format_Indexed8
		if len(image.shape) == 3: #
			if image.shape[2] == 4:
				qformat = QtGui.QImage.Format_RGBA8888

			else:
				qformat = QtGui.QImage.Format_RGB888
				#print(image.shape[0], image.shape[1], image.shape[2])
		self.img_2_display = QtGui.QImage(image, image.shape[1], image.shape[0], image.strides[0], qformat)
		self.img_2_display = QtGui.QImage.rgbSwapped(self.img_2_display)

		if window == 1:
			self.ui.imgLabel.setPixmap(QtGui.QPixmap.fromImage(self.img_2_display))
			self.ui.imgLabel.setScaledContents(False)

	# Save image to set location
	def save_image(self):
		if not os.path.exists("./images"):
			os.mkdir("images")

		self.date_string =  datetime.now().strftime("%Y-%m-%d %H:%M:%S")

		# Replace semicolons with underscores
		self.date_string = self.date_string.replace(":","_")
		self.write_image_loc = './images/'+self.date_string + '.png'
		cv2.imwrite(self.write_image_loc, self.image)
		self.statusBar().showMessage("Captured Image, saved to: " + self.write_image_loc)


	# Stop camera
	def stop_camera(self):
		self.timer.stop()

	# ======================
	# FUNCTIONS : Setup
	# ======================

	# Populate the available ports
	def populate_ports(self):
		print("Populating ports..")
		if sys.platform.startswith('win'):
			ports = ['COM%s' % (i + 1) for i in range(256)]
		elif sys.platform.startswith('linux') or sys.platform.startswith('cygwin'):
			# this excludes your current terminal "/dev/tty"
			ports = glob.glob('/dev/tty[A-Za-z]*')
		elif sys.platform.startswith('darwin'):
			ports = glob.glob('/dev/tty.*')
		else:
			raise EnvironmentError('Unsupported platform')

		result = []
		for port in ports:
			try:
				s = serial.Serial(port)
				s.close()
				result.append(port)
			except(OSError, serial.SerialException):
				pass
			self.ui.port_DROPDOWN.addItems(result)
			print("Ports have been populated.")

	# Refresh the list of ports
	def refresh_ports(self):
		self.statusBar().showMessage("You clicked REFRESH PORTS")
		self.ui.port_DROPDOWN.clear()
		self.populate_ports()
		self.set_port()

	# Set the port that is selected from the dropdown menu
	def set_port(self):
		self.port = self.ui.port_DROPDOWN.currentText()
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
